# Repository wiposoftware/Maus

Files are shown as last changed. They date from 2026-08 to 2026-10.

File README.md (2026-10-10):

# MAUS
## A RC paramotor gondola / pod / harnas / flightsystem
### Maus is a 3D printable opensource RC paramotor project
Maus 3D print rc paramotor gondola
Maus 3D print rc paramotor pod
Maus 3D print rc paramotor harnas
<br \>
Maus rc paramotor gondola
Maus rc paramotor pod
Maus rc paramotor harnas<br />
<br /><br />

**The Maus gondola is designed for:** <br />
 - RC paramotor wings size 1.0m² to 1.5m²<br />
 - AUW from 0.9kg up to 1.7kg<br />
 - 2 or 3 cell lipos<br />
 - brushless motors size 28mm & 35mm diameter, length up to 36mm<br />
 - servos size standard 40x20 mm or smaller 35x15 mm<br />
<br /><br />

**chosing the right setup:** <br />
After 3D printing the MAUS gondola, you will have a pod with a weight arround 300 ot 400 grams.<br />
This is an important factor in calculating your motor/esc/lipo setup and the AUW for your Maus flightsystem. The AUW must match your RC paramotor wing.<br />
The Maus gondole has 4 servo bays. <br />
- 2 for steerling/braking lines
- 2 for speedbar lines. <br />
Speedbar is an optional feature that not all RC paramotor wings have. If you do use speedbar servos, use low profile servos.
By using low profile servors on the bottom the MAUS pod can accomodate battery up to 3 cell 4200Mah!<br />
Maus gondola servo and battery tray
Maus pod servo and battery tray<br />
<br /><br />

**Prototype / tested setup:** <br />
- motor : HK 2836 2700Kv <br />
- prop : 9x4 folding <br />
- esc : HK 60Amp <br />
- servo : 2 x KST CM653 low profile <br />
- lipo : 4000Mah 2Cell (XT90) <br />
- AUW for prototype 1100 gram <br />
- Wing : Cefics CrossAlps 1.0 <br />
Maus 3D printable flight system<br />

<br /><br />
**Building instructions:** <br />
<br />
*Start with 3D printing all the parts* <br />
- Step 1: [follow instructions for the motor mount](1_MOTOR_MOUNT/README.md) <br />
- Step 2: [follow instructions for the servo mount](2_SERVO_MOUNT/README.md) <br />
- Step 3: [follow instructions for the mid section](3_MID_SECTION/README.md) <br />
- Step 4: [follow instructions for the back section](4_BACK_SECTION/README.md) <br />
- Step 5: [follow instructions for the front section](5_FRONT_SECTION/README.md) <br />
- Step 6: [check if you need to print some miscellaneous parts](6_MISC/README.md) <br />
<br />

*Mount all your electronics* <br />
 - Step 7: Connect the motor to the esc and insert esc and motor in the backsection of the MUAS gondola. <br />
 - Step 8: Insert the servos in the servo bays (mid section).<br />
 - Step 9: Connect servo arms to the servos.<br />
 - Step 10: Connect everything to your RX.<br />
 - Step 11: Insert the lipo.<br />
 - Step 12: Connect battery and power on your electronics, check that everything is working correctly.<br />
 - Step 13: Attach your RC paramotowing , brake lines , speedbar. [check info on hangbar](6_MISC/README.md) <br />
 - Step 14: Connect prop<br />
 - Step 15: Have a good flight.<br />

 maus gondola flying
 maus pod flying<br />
<br />
video of maiden flight <br />

MAUS RC Paramotor pod (https://www.youtube.com/watch?v=DP0582MmUQU)

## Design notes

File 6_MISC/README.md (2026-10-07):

# MAUS
## A RC paramotor gondola / pod / harnas / flightsystem

### Miscellaneous parts
these parts are not mandatory. Depending on your setup these might be usefull
<br/><br/><br/>
<ins>***Servo Cover***</ins><br/>
When you do not use the bottom servos (no speedbar functionality) you can print these covers to close the bottom servo holes.
The cover has an eliptical pocket for better grip when launching the Maus gondola. 
Download and print the "servero_cover.stl" file if you used default measurments for your servo's troughout this project.
If you want to change size en and servo hole distance download the "servo_cover.fcstd" file and use FreeCad to change the parameters<br />
Maus gondola servo cover<br />
Maus gondola servo cover<br />
<br /><br />
<ins>***Hang bar***</ins><br/>
The RC paramotor wing needs to be mounted to the Maus harnas. This project does not include a hang bar to attach the paramotor wing to the Maus flightsystem.
3D printed parts may be to weak for this job. Just go to your local hardware supply and find some metal brackets suitable for this project.
The width of the hang bar must match your RC paramotor wing. The brackets must be mounted to the Maus gondola in such a way that the total CG is correct. In hang the Maus harnas should be horizontal or the nose should point a litle bit downward.
Maus gondola 3D print hang bar
Maus pod 3D print hang bar
Maus harnas 3D print hang bar

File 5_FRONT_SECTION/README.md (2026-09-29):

# MAUS gondola/pod Front section

## Overview
The front of the MAUS gondola consists of three parts:
  - the cockpit
  - the nose cone
  - the canopy
<br/>
Currently, only an STL file is available for each component.

## Guide
### step 1 
Download the "frontsection.stl" file and use it in your 3D slicer program to print this part on a 3D printer.
I used 3 lines for wall thickness and 33% infill.

### step 2 
Use a good epoxy glue and glue it to the mid section part.<br/>
Maus gondola cockpit, front section<br/><br/>

### step 3
Download the "nose.stl" file and use it in your 3D slicer program to print this part on a 3D printer.
I used 3 lines for wall thickness and 33% infill.

### step 4
Use a good epoxy glue and glue it to the front section part.<br/>
Maus gondole nose cone, front section<br/><br/>

### step 5
Use a good epoxy glue and glue in 2 magnets. max size 12x7mm and 2mm thikness
The magnets will hold the canopy in place during flight.<br/>
Maus gondole cockpit magnets<br/><br/>

### step 6
Download the "canopy.stl" file and use it in your 3D slicer program to print this part on a 3D printer.
I used 3 lines for wall thickness and 33% infill.

### step 7
Do NOT glue the canopy in place! :)
Test fit the canopy. Due to 3D printing tolerances, you may need to sand down certain sides slightly.
When the canopy fits perfectly you can add 2 magnets (size 12x7x2mm) to the canopy. You can glue the magnets in place or you can just use tape and wrap it arround the magnet holder.<br/>
Maus gondola canopy<br/><br/><br/><br/>
maus_3d_print_side_view

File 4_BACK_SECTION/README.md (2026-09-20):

# MAUS gondola/pod BACK section

## Overview
There is little to say about the back section. This is the section where the ESC and motor are mounted.
Currently, only the .stp file is available (no FreeCAD file).

## Guide
### step 1 
Download the "backsection.stl" file and use it in your 3D slicer program to print this part on a 3D printer.
I used 3 lines for wall thickness and 33% infill.<br />
backsection<br /><br />

### step 2 
When this part is printed you have to insert 6 x M3 inserts. These inserts need to be pushed from the inside. 
Using M3 inserts is not mandatory. You can also mount the motor backplate using a screw and nut, but given the limited space, that is not exactly easy.<br />
backsection1<br /><br />

### step 3
Once the M3 inserts are installed, you can check whether the motor backplate and the motor fit into this part. If everything fits correctly, set the motor and backplate aside.<br />
backsection2<br /><br />

### step 4
Now use a good Epoxy glue to glue this back section part to the mid section part. The 7 mm wide joint, in combination with epoxy, can support sufficient weight/load.
DO NOT use CA glue! CA is not strong enough and your gondala will break. <br />
mid-back-glued<br /><br />

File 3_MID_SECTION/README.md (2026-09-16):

# MAUS gondola/pod MID section

## Overview
The central section of the Maus gondola is the part where the servos are mounted and to which the suspension bracket for the paraglider wing is to be attached later.
The Maus RC paramotor gondola supports mini (35.5x15) and standard (40x20) servos.<br/>

## Guide
### step 1 
If you used standard sizes in the previous steps, you can download the Midsection_yyxzz.stl file. Choose the file that matches your servo size. When 3D printing, you can experiment with the infill percentage and wall thickness. My POD was printed with 33% infill and a wall thickness of 3 lines.<br /><br/>
If you used different servo dimensions in previous steps, download the "maus_midsection.FCStd" file and open it in FreeCAD. Just like in the previous steps, you can adjust the dimensions using the selection boxes; no 3D design knowledge is required. After adjusting the dimensions, you may need to click the refresh button. Then, export the file to STL and 3D print it.<br />
maus gondel pod mid section<br /><br/>

### step 2 
Once this part has been printed, it is a good time to test-fit the servos.<br/>
Position the servos with their brackets and screw them in place temporarily. Check that everything fits and aligns properly.<br/>
If this is not the case, you may need to adjust the dimensions and reprint the part.<br/>
If everything is correct, remove the servos.<br/>

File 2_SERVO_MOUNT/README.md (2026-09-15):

# Servo brackets

## Overview
The Maus RC paramotor gondola supports mini (35.5x15) and standard (40x20) servos.<br/>
Within a given class, a servo's dimensions may differ slightly from the standard size. Before 3D printing the Maus gondola, it is crucial to test the servo fitting and note down the exact dimensions. <br/>
This repository contains two STL files: one for mini servos and one for standard servos. These STL files feature default dimensions typical for their respective classes.

## Guide
### step 1 
Download the "servo_fit_xxxx" STL file that corresponds to your servo class. Use the STL file in your 3D printer slicer software to print the test plate.<br />
stb1
stb2<br />

### step 2
Check that your servo fits properly into the test plate and that the servo mounting holes align with the holes in the test plate.<br />
stb3
stb4
stb5<br />

If this is not the case, adjust the dimensions of the test plate and print it again. **Repeat this step until your servo fits perfectly.**

To change the test plate dimension download the "servo_fit_test.FCStd" file use FreeCad to open it and change the values. You don't need any 3D design knowledge; dimensions can be adjusted using a simple selection box. Then, export your modifications to a new STL file and use it in your 3D printer slicer software.<br />
stb6<br />

### step 3
Okay, you have found the correct dimensions for the servo mount and noted down the values. We will not need this mount any further for the assembly of the Maus gondola.<br /><br />
The servos can be mounted in the gondola using screws and bolts; however, the limited space can make this a difficult task. To simplify the servo installation, a mounting aid is provided in the next step.

### step 4
If you used the default values in the previous steps, you can download the "servo_bracket.stl" file and print it on your 3D printer.<br />
If you used custom values, you can download the "servo_bracket.FCStd" file and adjust the settings in FreeCAD—again, using simple selection boxes. Then, export to STL and print.<br />
<br />
servo_bracket<br /><br />

### step 5
For this bracket, I recommend using M3 threaded inserts (the default option). You can also use standard screws and nuts, though assembly is more difficult.<br />
servo_bracket1<br /><br />

### step 6
Use tape to temporarily attach the servo mounting brackets to the servo. Make sure the M3 inserts are facing downwards.<br />
servo_bracket3
servo_bracket2<br /><br />

### step 7
Now, use the servo-fitting template from step 1 one last time. Use a few screws to check that all parts and holes align perfectly.<br />
If they do not align, you will need to adjust the dimensions of the mounting template and print it again.<br />
servo_bracket4
servo_bracket5<br /><br />

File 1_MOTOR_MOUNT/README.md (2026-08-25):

# Motor mount backplate

## Overview
The motor needs to be mounted on a flat plate at the back of the Maus gondola. This plate must be made of a strong material, such as metal, carbon fiber, or fiberglass, and be 1.5 to 2 mm thick. A plastic plate would wear out, break, or warp too quickly.

The 3D design/print in this repository is a template you can use to create a backplate from a strong material using simple tools like a handsaw and a drill; no CNC is required.

The STL files in this repository contain the 3D design that you can use directly in your 3D printer slicer software to print the template. There is one STL file for motors with a 16x19 mounting hole pattern (common for 28xx size brushless motors) and another for motors with a 25x25 pattern (common for 35xx size brushless motors)

If your motor has a different layout, or if you wish to adjust the template's dimensions (such as thickness or height), you can do so by opening the FCStd file in FreeCAD. You do not need any 3D design experience; these adjustments can be made simply by using a convenient selection box. Once you have made the changes, click "Export" and select STL (or another format compatible with your 3D printer slicer software).
motormountfreecad
<br/>

## Guide

### Step 1
3D print the template<br/>
Maus Gondola motor mount template 3D printed<br/>

### Step 2
Apply double-sided tape to the back of the 3D print.<br/>
Maus Gondola motor mount template 3D printed<br/>

### Step 3
Now stick the template onto your strong material (metal, carbon, fiberglass)..<br/>
Maus Gondola motor mount template 3D printed
Maus Gondola motor mount template 3D printed<br/>

### Step 4
Now saw away the excess material around the template. And use a <ins>2mm drill</ins> bit to drill the holes.<br/>
mmt5
mmt6
mmt7
<br/>

### Step 5
Drill the holes to the correct size. Outer holes must be 3mm. Size of inner holes should be according to your motor mounting hols size. And center hole should sized to your motor shaft.<br/>
mmt8
<br/>

### Step 6
Attach the motor to the backplate.<br/>
mmt9<br/>

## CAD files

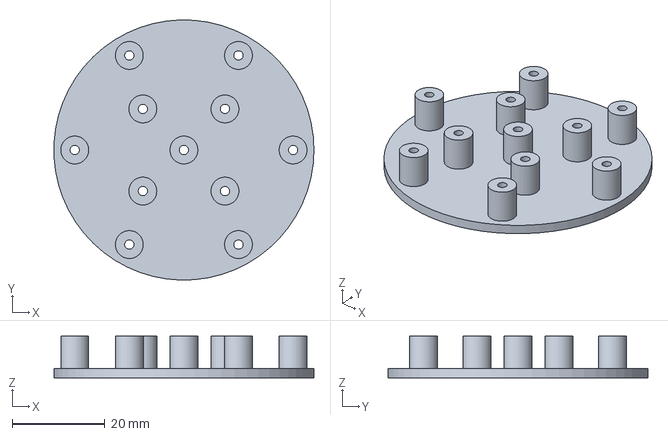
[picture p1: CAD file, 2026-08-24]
1_MOTOR_MOUNT/motor_mount_template.FCStd
56.0 x 56.0 x 9.00 mm

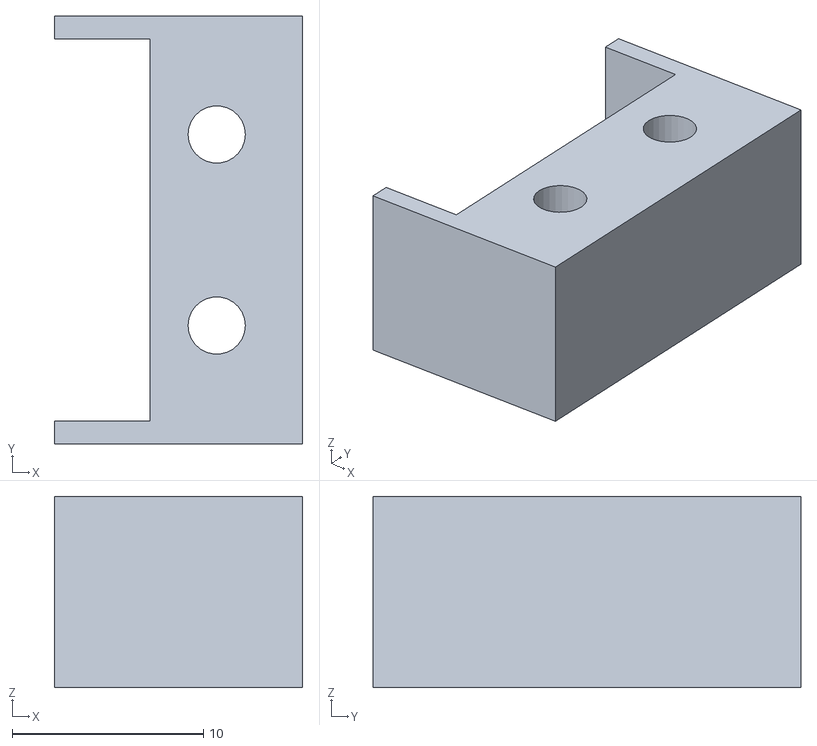
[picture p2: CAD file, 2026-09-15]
2_SERVO_MOUNT/servo_bracket_40x20.stl
13.0 x 22.4 x 10.0

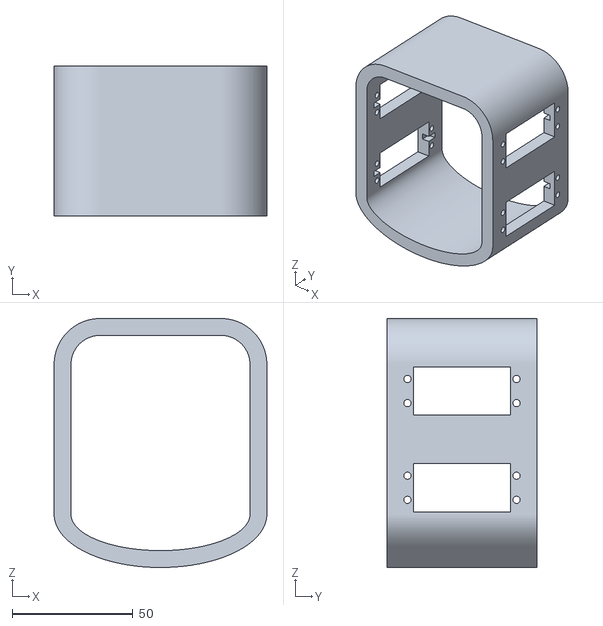
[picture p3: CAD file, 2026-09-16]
3_MID_SECTION/MidSection_40x20.stl
88.0 x 62.0 x 103.0

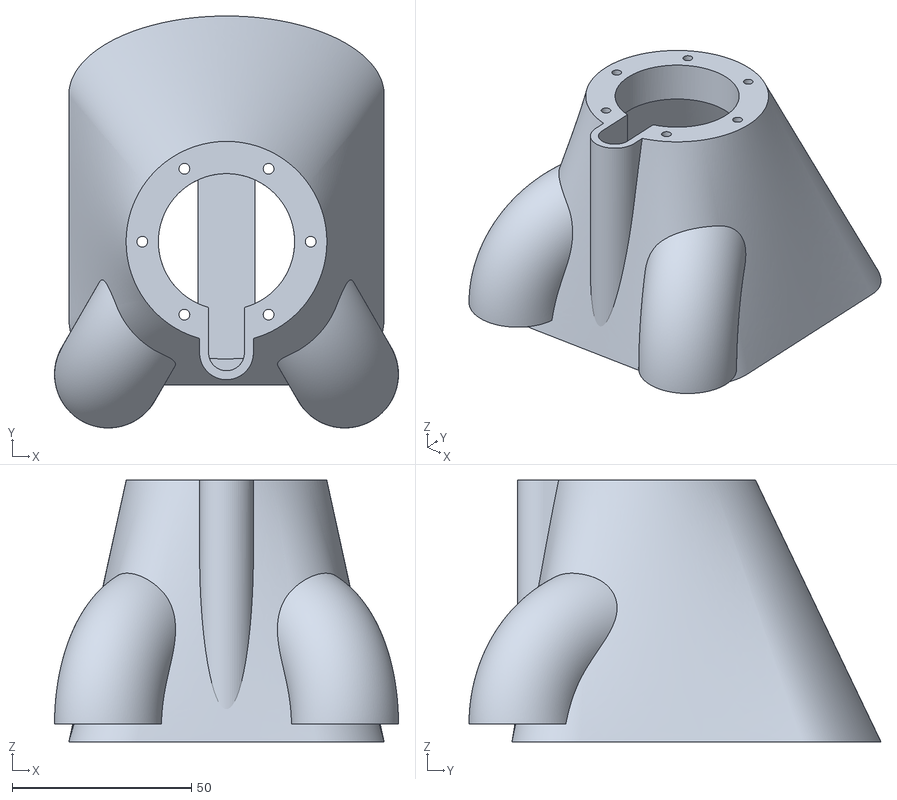
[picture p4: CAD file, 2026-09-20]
4_BACK_SECTION/BackSection.stl
96.0 x 115.0 x 73.0

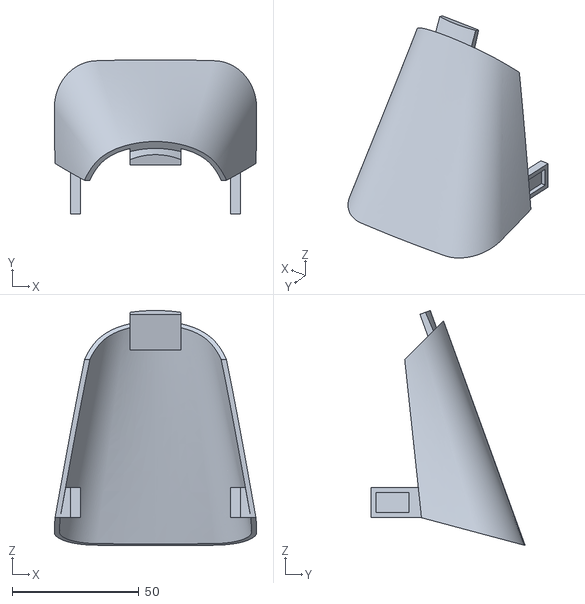
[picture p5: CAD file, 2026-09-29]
5_FRONT_SECTION/Canopy.stl
79.8 x 60.9 x 92.6

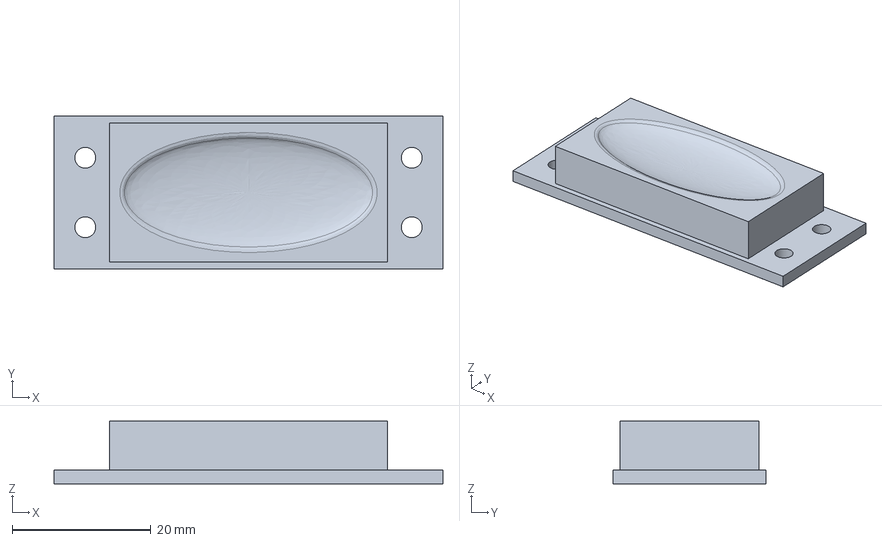
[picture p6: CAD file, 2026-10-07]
6_MISC/servo_cover.FCStd
56.0 x 22.0 x 9.00 mm

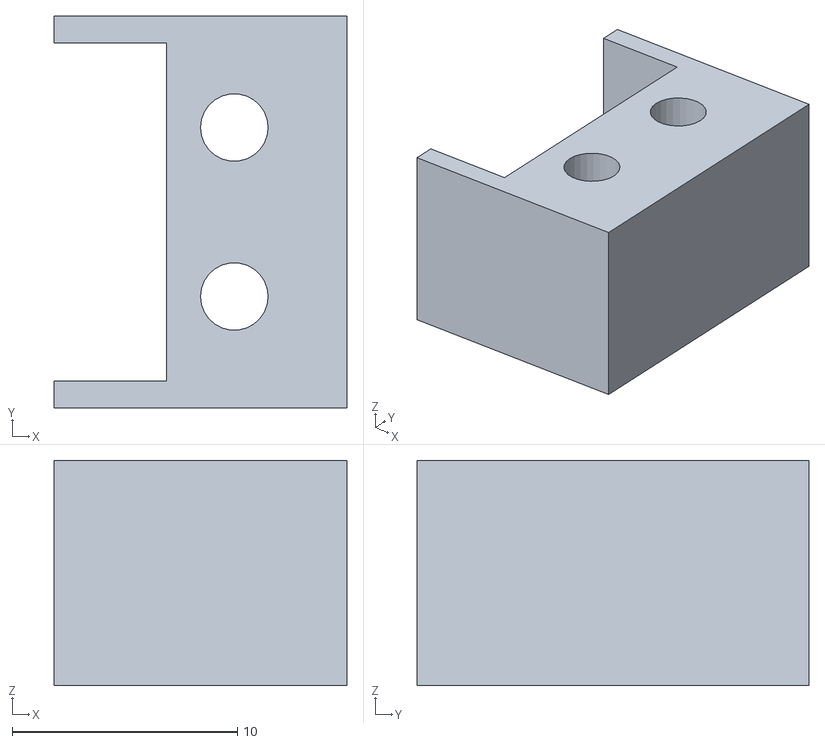
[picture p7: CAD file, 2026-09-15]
2_SERVO_MOUNT/servo_bracket_35x15.stl
13.0 x 17.4 x 10.0

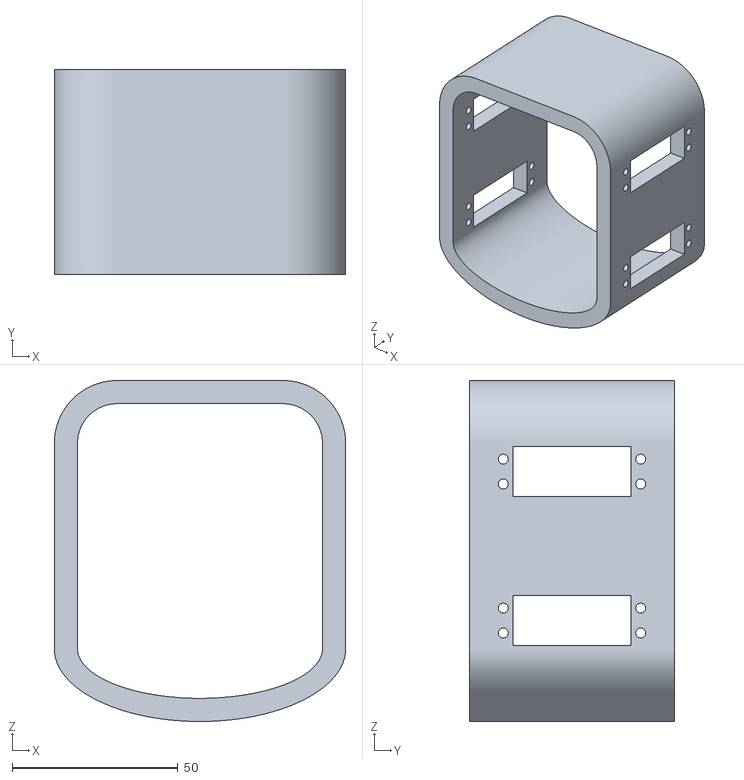
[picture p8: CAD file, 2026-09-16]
3_MID_SECTION/MidSection_35x15.stl
88.0 x 62.0 x 103.0

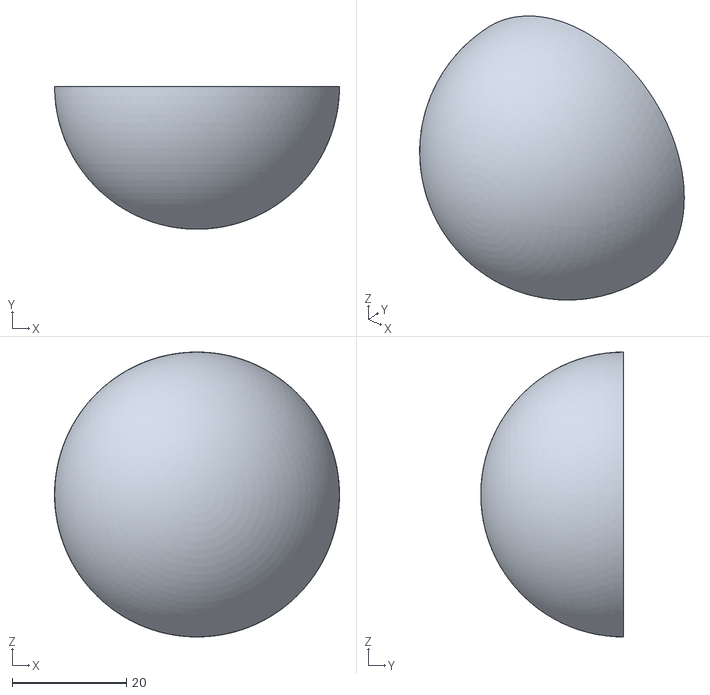
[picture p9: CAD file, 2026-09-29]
5_FRONT_SECTION/Nose.stl
50.0 x 25.0 x 50.0

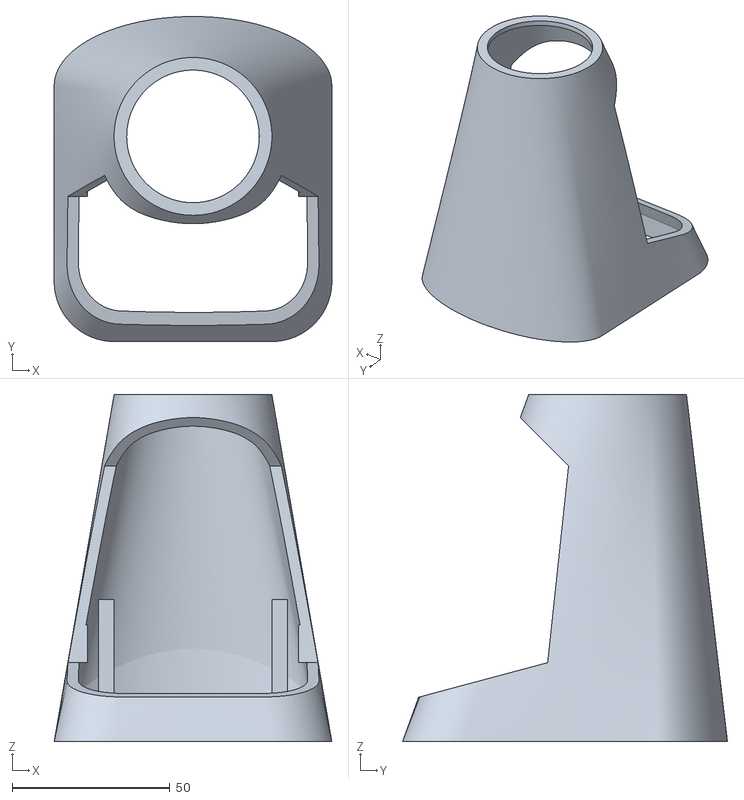
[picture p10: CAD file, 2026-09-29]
5_FRONT_SECTION/FronSection.stl
88.0 x 103.0 x 110.0

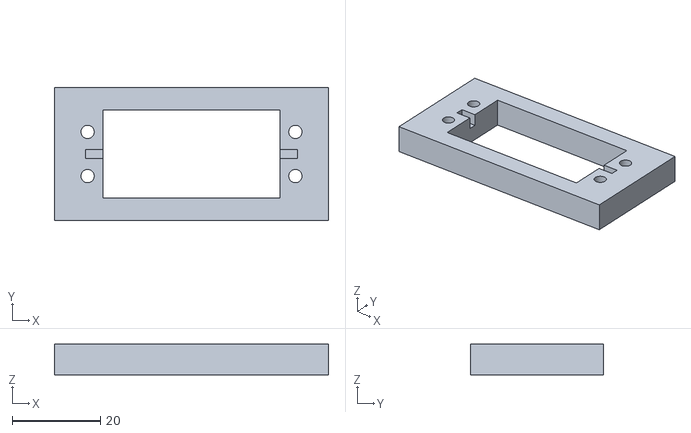
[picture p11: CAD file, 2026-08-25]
2_SERVO_MOUNT/servo_fit_40x20.stl
62.0 x 30.0 x 7.00

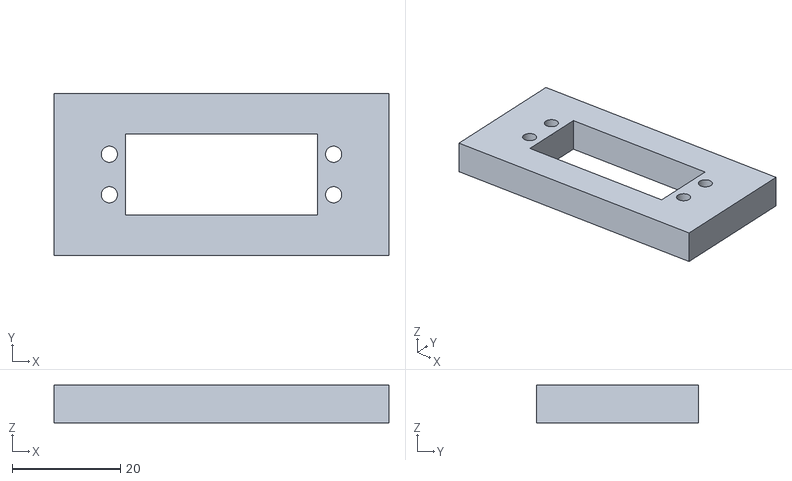
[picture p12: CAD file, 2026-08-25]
2_SERVO_MOUNT/servo_fit_35x15.stl
62.0 x 30.0 x 7.00

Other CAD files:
1_MOTOR_MOUNT/motor_mount_25x25.stl
1_MOTOR_MOUNT/motor_mount_16x19.stl
2_SERVO_MOUNT/servo_bracket.FCStd
3_MID_SECTION/maus_midsection.FCStd
2_SERVO_MOUNT/servo_fit_test.FCStd
6_MISC/servo_cover.stl

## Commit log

2026-08-25 Motor mount installation guide
    Added detailed instructions for creating and installing the motor mount backplate, including material specifications and step-by-step guide with images.
2026-08-25 Create servo dir
2026-09-15 Expand README with detailed servo mounting steps
    Added additional steps for servo mounting process, including recommendations for assembly and adjustments.
2026-10-07 Update README with servo cover details
    Added information about the servo cover for the gondola.
